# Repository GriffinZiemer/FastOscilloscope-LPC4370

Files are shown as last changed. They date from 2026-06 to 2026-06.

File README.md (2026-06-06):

# 34 MSa/s Dual Channel Oscillscope
A custom design dual channel USB-C oscilloscope built around the NXP LPC4370 (100 pin TFBGA) intended to output to a Python-based graphical display on a connected computer driven by PyQtGraph. The oscilloscope was designed for the Oregon State University Junior Design II course (ECE 342), the project took place over a 10 week term. 
<p float="left">

<img width="1000"" alt="Screenshot 2026-06-05 142354" src="https://github.com/user-attachments/assets/b3b1693e-237f-446d-a00e-379146662170" />
</p>

# Contributors:
Luke Neilson,
Griffin Ziemer, and
Cooper Holm

## Key Features:
* Dual Channel Simulatnuous Sample Rate: 34MSa/s.
* Vertical Resolution: 12-bits.
* Bandwidth: 1MHz.
* Input Voltage Range: +/- 10V with a 10x attenuation probe, +/- 1V with a 1x attenuation probe.
* AC/DC Coupling: Hardware AC/DC coupling using a photo relay to bypass a 100nF capacitor.
* Power: Powered entirely via a standard USB 2.0 connection (nominally drawing 180mA), with a visible LED power indicator.
* User Interface: High-speed display which responds to user input in an average of 0.350 milliseconds

## Hardware Architecture
* Power Block: 5V USB input regulated down to 3.3V digital rail using a TpS79533 LDO. An LM27762 charge pump provides +/- 1.65V rails for some of the Analog Front End op-amps. A 500mV Vref offset is generated off a ferrite bead from the 3.3V line.
* Analog Front End: Incoming signals pass through the coupling and overvoltage protection stages into a variable gain attenuation controlled by TMUX1134 precision analog multiplexers. OPA356 op-amps shift and scale the signals to fit the 100mV to 900mV window required by the LPC4370's ADC.
* Microcontroller: The system uses an LPC4370's Direct Memory Access controller to write 12-bit ADC results into an SRAM buffer without CPU overhead, ensuring maximum throughput.

## Software & Protocol Stack
* Firmware: The backend firmware configures the Analog Front End Gain and AC/DC photorelays at boot. It serializes DMA transfers into packets containing 0xAA start byte, the daya type, sample count, payload and an XOR checksum, transmitting them over a USB CDC link.
* Host Bridge & GUI: A worker thread deserializes incoming packets, verifies the checksum, and translates raw ADC counts into real voltage based on the current user scale. The UI is built using PyQt5 and pyqtgraph. To maximize accessibilty, Channel 1 is rendered in blue and Channel 2 in pink, complying with NCEAS colorblind-safe guidelines.

## Team Work Breakdown
* Luke Neilson: MCU block design, PCB layout (Versions 1 and 2), initial Display blcok design, and Teensy 4.0 backup implementation.
* Griffin Ziemer: User Input GUI, Backend firmware, host bridge protocol serialization/deserialization, and integration of the display.
* Cooper Holm: Power supply block design, Analog Frent End architecture.

## Future Improvements
 ### To Be Implemented with Current Hardware
  Due to the 10 week timeline, the project ran out of time to implement all of the features designed in hardware in the software.
  * Real time control over the attenuation paths, allowing selection between gain path: 0.256x, 0.833x, 2.566x, and 10x
  * Real time control over AC/DC coupling, allowing selection between gain path: 0.256x, 0.833x, 2.566x, and 10x
  * Configure PLLs to create an exact 80MHz clock for the ADC to reach the maximum hardware sampling rate
  * Flash firmware to the non-volitile memory
 ### Version 3 of the PCB Improvements
  * Minimize digital analog cross talk: The bandwidth was limited because a more aggressive RC filter at the ADC input was required because of the noise from the digital components (LPC 4370 and a 12MHz external clock).
   * Shorten the signal path from the analog front end to the ADC.
   * Use differential pair drivers to create differential pairs to go from the analog front end to the ADC

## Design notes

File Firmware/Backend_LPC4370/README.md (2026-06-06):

# Backend_LPC4370 (LPC4370 Firmware)

This is the Backend block for the FastOscilloscope project, written as C firmware that runs on the LPC4370 MCU. It does four things:

1. Brings up the system clock (12 MHz crystal to 204 MHz core, 68 MHz HSADC)
2. Drives the analog front end GPIOs (gain MUX plus AC/DC coupling)
3. Captures bursts of 12 bit ADC samples via the on chip HSADC
4. Talks to the laptop over USB CDC using our framed packet protocol

On the laptop side, `Code/host_bridge.py` speaks the same protocol and hands packets to the User Input and Display blocks.

## Status, read this before flashing

I want to be upfront about what's actually done. The firmware is structurally complete. Every file the project needs exists, every function the build references is defined, and the byte level protocol is fully cross validated against the laptop side with no hardware (see "Verifying it works" below).

What's NOT done yet:

* I haven't compiled it in MCUXpresso on a Windows box, only laptop side static analysis. So a couple of include paths or library link names may need small tweaks once the project is imported.
* The DMA routing from the HSADC FIFO into SRAM goes through the LPC4370's GIMA (DMA mux). LPCOpen ships no LPC4370 specific example for this and I wasn't going to guess. Fallback is polled reads from `HSADC->LAST_SAMPLE` for the first bring up, see TODOs.
* Has not been run on real silicon. Pin map values came from Luke's schematic but I'd verify a couple with a multimeter before flashing.

So: this gets you a project that compiles and links into a flashable binary. Whether HSADC samples actually land in the right buffer at the right rate is a hardware day discovery.

## Source layout

```
Firmware/Backend_LPC4370/
|-- inc/
|   |-- pin_map.h          Named pin defines from Luke's pin assignment table
|-- src/
|   |-- main.c             Superloop: drain USB RX, parse, dispatch, push USB TX
|   |-- proto.[ch]         Packet parser/builder (must match host_bridge.py byte by byte)
|   |-- afe.[ch]           AFE GPIO control (gain MUX, AC/DC coupling switch)
|   |-- adchs.[ch]         HSADC init plus DMA driven burst capture plus trigger comparator
|   |-- clock.[ch]         CGU setup: 204 MHz core (PLL1), 68 MHz HSADC (IDIVA from PLL1)
|   |-- usb_cdc.[ch]       Thin wrapper around the vendored LPCOpen CDC code
|   |-- lpcopen_cdc/       Vendored LPCOpen USB CDC sources (see header below)
|       |-- app_usb_cdc.c  Refactored from LPCOpen's cdc_main.c (USB stack init)
|       |-- cdc_vcom.c/.h  Virtual COM port class implementation
|       |-- cdc_desc.c     USB device plus endpoint descriptors
|       |-- app_usbd_cfg.h ROM driver config plus USB stack memory layout
|       |-- board.h        Tiny shim so the vendored files compile without bambino
```

`lpcopen_cdc/` is the LPCOpen `usbd_rom_cdc_vcom` example, copied in and refactored so we expose `app_usb_cdc_init()` instead of a `main()`. NXP's permissive license is in each file's header.

## What you need installed first

On the host (the machine you'll build firmware on):

* MCUXpresso IDE, NXP's Eclipse based IDE for LPC parts. https://www.nxp.com/.../mcuxpresso-software-and-tools-:MCUXpresso-IDE
* LPCOpen LPC18xx/43xx package. Provides `lpc_chip_43xx`, the chip driver library we link against. NXP's download requires a free account. The file we want is something like `lpcopen_3_02_lpcxpresso_nxp_lpcxpresso_4337.zip`.
* An SWD debug probe (LPC-Link2, J-Link, or equivalent).

On the laptop you'll talk to the board with:

* Python 3.10 or newer
* `pip install pyserial pyqt5 pyqtgraph numpy`
* The COM port the board enumerates as. Look in Device Manager, Ports on Windows, or `ls /dev/tty.usbmodem*` on macOS/Linux.

## How to build it

### 1. Pull LPCOpen into MCUXpresso

In MCUXpresso click "Import project(s) from file system" in the Quickstart Panel, point at the LPCOpen zip, and check `lpc_chip_43xx` in the import dialog. Build it once. You should see a green `lpc_chip_43xx.a` show up under `Debug/`.

You do NOT need to import LPCOpen's CDC example. We vendored it in `src/lpcopen_cdc/` so we don't depend on it being available.

You also do NOT need to import a `lpc_board_*` library. We wrote our own minimal board init (it's inside `clock.c` plus `afe_init()` plus the vendored `board.h` shim).

### 2. Create the Backend project

1. File, New, C Project, NXP, LPC4300, LPC4370.
2. Empty Project template. Don't let it copy in any LPCOpen sources. We want our own `src/` and `inc/` to be the only sources.
3. Set the project location to this folder (`Firmware/Backend_LPC4370`). MCUXpresso writes `.cproject` and `.project` here.

### 3. Wire up the includes plus library link

In Project Properties, C/C++ Build, Settings:

* MCU C Compiler, Includes: add
  * `../inc`
  * `../../lpc_chip_43xx/inc`
  * `../src/lpcopen_cdc` (so `#include "cdc_vcom.h"` and friends resolve)
* MCU Linker, Libraries: add `lpc_chip_43xx` under Libraries (-l) and the matching `Debug` or `Release` path under Library search path (-L).
* Project References: tick `lpc_chip_43xx` so it rebuilds when needed.

### 4. Build

Right click the project, Build Project. You should get a clean build with no warnings about missing functions. If you see `undefined reference to vcom_*` or `find_IntfDesc`, check that `src/lpcopen_cdc/` was added to the source folders. Sometimes MCUXpresso misses subdirs.

### 5. Flash

1. Connect the SWD probe (TMS/SWDIO, TCK/SWDCLK, GND, VTREF).
2. Run, Debug As, MCUXpresso IDE LinkServer Debug.
3. Make sure the boot button (P2_8) is NOT held down at reset.

## First time on hardware, staged bring up

Don't go straight to "run main.py and look at waveforms." Things will fail and you won't know where. Do these milestones in order. Each one de risks the next.

**Milestone 1: blink the Neopixel.** Add a temporary 1 Hz toggle on `NEOPIXEL` (P1_6) before `usb_cdc_init()` in `main()`. If the LED blinks, your toolchain plus flash plus clock are working. Remove the test code when done.

**Milestone 2: USB enumerates.** With main() back to normal, plug the USB cable into the laptop. Open Device Manager (Windows) and watch for a new "USB Serial Device (COMx)". If it shows up, the CDC stack is alive.

**Milestone 3: command bytes round trip.** With the device enumerated, from the laptop:
```
python Code/tests/test_host_bridge.py --port COM5 --log-packets
```
You should see TX packet hex traced, and ideally no errors. This proves the host can write bytes that reach the device's USB stack.

**Milestone 4: AFE pins toggle.** Put a scope or multimeter on `CH1_SEL1..4`. Send a few `set_vdiv` commands from `Code/main.py` and watch the SEL lines flip one hot. The `afe_set_gain()` function is strictly break before make so you should never see two SELs high at the same time.

**Milestone 5: HSADC produces data.** Feed a known DC voltage (1.0 V from a battery or bench supply) through the AFE input. Send `set_vdiv` 1 V/div, then `run`. The Display should show a flat line at roughly 1.0 V. If it shows zero or noise, the issue is in the HSADC config (probably the DMA routing, see TODOs).

**Milestone 6: real waveform.** Function generator into AFE input, live waveform on `python Code/main.py --port COM5`. This is the "Backend block fully works" demo.

## Verifying it works

Some of this you can verify before hardware exists. The protocol layer is fully testable on a laptop.

### Without hardware (works on any laptop right now)

```
# All 6 host side tests
python Code/tests/test_host_bridge.py --all

# Cross validate firmware proto.c against host_bridge.py (Test 7)
# Requires gcc on PATH; on Windows install MinGW w64
Code\tests\native\build_proto.bat
python Code\tests\test_proto_parity.py

# AFE control logic unit test (Test 8)
# Same gcc requirement; compiles firmware afe.c against mocked GPIO calls
Code\tests\native\afe_test\build_afe.bat
python Code\tests\test_afe_unit.py
```

Test 7 compiles our actual firmware `proto.c` into a DLL, loads it via ctypes, and checks that every command and data packet round trips byte by byte between the C and Python implementations. Test 8 does the same trick with `afe.c`, recording every GPIO call and verifying the break before make and one hot rules hold. Together they fully verify the protocol and AFE control layer properties of all three Backend interfaces without ever touching hardware. Worth running before plugging the board in just to confirm your environment is sane.

### With hardware

```
# Same test, real device
python Code/tests/test_host_bridge.py --port COM5 --log-packets
python Code/tests/test_host_bridge.py --port COM5 --verify-checksums
python Code/tests/test_host_bridge.py --port COM5 --debug-threads
```

Tests 4 and 5 (inject known patterns or corrupt packets) stay on MockMCU because they need to control the MCU's outgoing bytes, which a real device won't let you do.

## Known issues and TODOs

These are real gaps, not "make sure to verify" stuff. They need work either on hardware or with the LPCOpen reference in hand.

| File | What's wrong or missing |
|---|---|
| `adchs.c` | DMA from HSADC FIFO into SRAM needs the LPC4370 GIMA setup. LPCOpen has no example. Fallback: polled reads from `HSADC->LAST_SAMPLE` in main superloop. |
| `adchs.c` | Sample rate math assumes BASE_ADCHS_CLK = 68 MHz exactly. Verify on hardware with a known input frequency. |
| `clock.c` | Should work as is but I haven't actually scoped the ADCHS clock pin to confirm 68 MHz. |
| `main.c` | Trigger comparator behavior is "best guess" from UM10503 section 47. The threshold to edge mapping might be inverted. Check with a known signal. |
| `usb_cdc.c` | If you see CDC TX truncation under load, bump `g_rxBuff` size in `app_usb_cdc.c` or add a software TX ring. Default is fine for command plus 2 KB ADC bursts. |

## Some implementation notes (for whoever picks this up next)

**Why 68 MHz on HSADC instead of 80 MHz?** 80 MHz from a 12 MHz crystal requires PLL0AUDIO with non integer M, N, P values, which I tried and gave up on. PLL1 divided by 3 gives an exact 68 MHz, uses only the documented `Chip_Clock_*` helpers, and still gives 165 times the project's 200 kHz per channel customer requirement. Swap in PLL0AUDIO later if we really need 80 MHz.

**Why is HSADC called ADCHS in our headers?** NXP's manual uses both names for the same peripheral. LPCOpen settled on `Chip_HSADC_*` and `LPC_HSADC`, so the C code does too. Our public API is `adchs_*` to match the team wide "ADCHS" terminology in the system block diagram.

**Why is the `set_trigger` command split into 3 packets on the wire?** Block 1's GUI emits one big `set_trigger` dict with level, mode, and source. The host side `serialize_command()` expands that into three back to back on wire packets (`SET_TRIGGER_LEVEL`, `SET_TRIGGER_MODE`, `SET_TRIGGER_SOURCE`) because (a) it keeps each packet at most 7 bytes and (b) it lets the firmware update one field without touching the others. The firmware caches all three and re applies the comparator on every update.

**Why is `afe_set_gain()` break before make?** Some analog MUXes are make before break and can briefly forward two signal paths to the ADC during a gain change. Driving all four SELs low first, then asserting the new one, gives us a clean (briefly silent) switch instead of a crosstalk glitch.

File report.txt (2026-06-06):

Info: X scale constrained.
Info: Y scale constrained.
Plotted to 'C:\Users\coope\Documents\ECE342\FastOscilloscope-LPC4370\KiCAD\MCU-F_Cu.gbr'.
Plotted to 'C:\Users\coope\Documents\ECE342\FastOscilloscope-LPC4370\KiCAD\MCU-In1_Cu.gbr'.
Plotted to 'C:\Users\coope\Documents\ECE342\FastOscilloscope-LPC4370\KiCAD\MCU-In2_Cu.gbr'.
Plotted to 'C:\Users\coope\Documents\ECE342\FastOscilloscope-LPC4370\KiCAD\MCU-B_Cu.gbr'.
Plotted to 'C:\Users\coope\Documents\ECE342\FastOscilloscope-LPC4370\KiCAD\MCU-F_Paste.gbr'.
Plotted to 'C:\Users\coope\Documents\ECE342\FastOscilloscope-LPC4370\KiCAD\MCU-B_Paste.gbr'.
Plotted to 'C:\Users\coope\Documents\ECE342\FastOscilloscope-LPC4370\KiCAD\MCU-F_Silkscreen.gbr'.
Plotted to 'C:\Users\coope\Documents\ECE342\FastOscilloscope-LPC4370\KiCAD\MCU-B_Silkscreen.gbr'.
Plotted to 'C:\Users\coope\Documents\ECE342\FastOscilloscope-LPC4370\KiCAD\MCU-F_Mask.gbr'.
Plotted to 'C:\Users\coope\Documents\ECE342\FastOscilloscope-LPC4370\KiCAD\MCU-B_Mask.gbr'.
Plotted to 'C:\Users\coope\Documents\ECE342\FastOscilloscope-LPC4370\KiCAD\MCU-Edge_Cuts.gbr'.
Created Gerber job file 'C:\Users\coope\Documents\ECE342\FastOscilloscope-LPC4370\KiCAD\MCU-job.gbrjob'.
Info: Done.

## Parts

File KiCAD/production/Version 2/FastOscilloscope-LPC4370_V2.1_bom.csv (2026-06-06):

Designator | Footprint | Quantity | Value | LCSC Part #
+1V65, -1V65, 1_SEL1, 1_SEL2, 1_SEL3, 1_SEL4, 2_SEL1, 2_SEL2, 2_SEL3, 2_SEL4, 3V3, 5V1, CHANNEL1, OFF1, SSR_1, SSR_2, TP12 | TestPoint_Pad_1.0x1.0mm | 17 | TestPoint
BNC1, BNC2 | BNC Connector 2.0 | 2 | 3GHz
BOOT1, RESET1 | KEY-SMD | 2 | Push Button
C1, C10, C11, C12, C16, C21, C23, C24, C26, C27, C28, C3, C30, C31, C32, C34, C36, C37, C38, C4, C40, C41, C42, C45, C47, C5, C6, C7, C8, C9 | 0402 | 30 | 0.1uF
C13, C18 | 0603 | 2 | 4.7uF
C14, C19, C20 | 0603 | 3 | 2.2uF
C15, C22, C44 | 0603 | 3 | 1uF
C17, C46 | 0603 | 2 | 10uF
C2, C48 | 0402 | 2 | 12pF
C25, C35 | 1206 | 2 | 100nF
C29, C39 | 0603 | 2 | 5pF
C33, C43 | 0603 | 2 | 330p
D1, D2 | SOT-23-3_L2.9-W1.6-P1.90-LS2.8-BR ESD | 2 | Diode Array
FB1 | L0603 (Ferrite Bead) | 1 | FerriteBead
LED1 | PSU LED | 1 | PSU LED
MCU1 | LPC4370 | 1 | LPC4370FET100E
NEOPIXEL1 | Neopixel | 1 | LED1
R1, R10, R11, R12, R6, R7, R9 | 0402 | 7 | 10k
R14 | 0603 | 1 | 75k
R15 | 0603 | 1 | 200k
R16 | 0603 | 1 | 68k
R17 | 0603 | 1 | 24k
R18, R30 | 0603 | 2 | 390
R19, R31 | 0603 | 2 | 1.2k
R2 | 0402 | 1 | 0
R20, R32 | 0603 | 2 | 3.9k
R21, R33 | 0603 | 2 | 470
R22, R34, R44 | 0603 | 3 | 100
R23, R35 | 1206 | 2 | 1M
R24, R36 | 0805 | 2 | 2k
R25, R26, R27, R28, R37, R38, R39, R40, RF1, RF2 | 0603 | 10 | 1k
R29, R41 | 0603 | 2 | 47
R42, R43 | 0603 | 2 | 5.1k
R8 | 0402 | 1 | 12k
U1 | Flash footprint 2.0 | 1 | Flash
U10, U13, U14, U15, U8, U9 | DBV5-OPAMP | 6 | OPA356AIDBVR
U11, U6 | VSON-4_L1.5-W2.5-P0.80-BL-DCAC-SWITCH | 2 | TLP3441TP_F
U12, U7 | TSSOP20_PW_TEX-MUX | 2 | TMUX1134PWR
U2 | PinHeader_2x05_P2.54mm_Vertical | 1 | Header
U3 | SOT-223-6_L6.5-W3.5-P1.27-BL (LDO2.0) | 1 | LDO
U4 | WSON-12_L3.0-W2.0-P0.50-BL-EP (Charge Pump) | 1 | LM27762DSSR
U5 | UJ_6_ADI | 1 | ADR130BUJZ-REEL7
USB2 | USB2.0 | 1 | USB1
Y1 | XTAL_ABM3B-12.000MHZ-10-1-U-T | 1 | Passive Oscillator

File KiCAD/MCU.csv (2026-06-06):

Reference | Value | Datasheet | Footprint | Qty | DNP | Supplier Part | Part type
BNC1,BNC2 | 3GHz | https://item.szlcsc.com/datasheet/DOSIN-801-0038/747625.html | JLCPCB_Custom_Parts:BNC Connector 2.0 | 2 | DNP | C709673 | Extended
C1,C2,C3,C4,C5,C6,C7,C8,C9,C10,C11,C12,C16,C21,C23,C24,C26,C27,C28,C30,C31,C32,C34,C36,C37,C38,C40,C41,C42,C45,C47 | 0.1uF |  | Capacitor_SMD:C_0402_1005Metric | 31 |  | C1525 | Basic
C13,C18 | 4.7uF |  | Capacitor_SMD:C_0603_1608Metric | 2 |  | C19666 | Basic
C14,C19,C20 | 2.2uF |  | Capacitor_SMD:C_0603_1608Metric | 3 |  | C23630 | Basic
C15,C22,C44 | 1uF |  | Capacitor_SMD:C_0603_1608Metric | 3 |  | C15849 | Basic
C17,C46 | 10uF |  | Capacitor_SMD:C_0603_1608Metric | 2 |  | C96446 | Basic
C25,C35 | 100nF |  | Capacitor_SMD:C_1206_3216Metric | 2 | DNP | C303949 | Extended
C29,C39 | 5pF |  | Capacitor_SMD:C_0603_1608Metric | 2 | DNP | C49326336 | Extended
C33,C43 | 330p |  | Capacitor_SMD:C_0603_1608Metric | 2 |  | C1664 | Basic
C48 | 100pF |  | Capacitor_SMD:C_0603_1608Metric | 1 |  | C14858 | Basic
D1,D2 | Diode Array |  | JLCPCB_Custom_Parts:SOT-23-3_L2.9-W1.6-P1.90-LS2.8-BR ESD | 2 |  | C2500 | Basic
FB1 | FerriteBead |  | JLCPCB_Custom_Parts:L0603 (Ferrite Bead) | 1 |  | C14709 | Basic
H1 | Debug Header |  | JLCPCB_Custom_Parts:Debug Header | 1 | DNP | C5155080 | Extended
LED1 | PSU LED |  | JLCPCB_Custom_Parts:PSU LED | 1 |  | C2290 | Basic
MCU1 | LPC4370FET100E | LPC4370FET100E | JLCPCB_Custom_Parts:LPC4370 | 1 |  | C1020255 | Extended
Neopixel1 | LED1 | https://item.szlcsc.com/datasheet/SKC6812RGBW-WS-B/6248995.html | JLCPCB_Custom_Parts:Neopixel | 1 | DNP | C5380879 | NA
R1,R4,R6,R7,R9,R10,R11,R12,R13 | 10k |  | Resistor_SMD:R_0402_1005Metric | 9 |  | C25744 | Basic
R8 | 12k |  | Resistor_SMD:R_0603_1608Metric | 1 |  | C22790 | Basic
R14 | 75k |  | Resistor_SMD:R_0603_1608Metric | 1 |  | C23242 | Basic
R15 | 200k |  | Resistor_SMD:R_0603_1608Metric | 1 |  | C25811 | Basic
R16 | 68k |  | Resistor_SMD:R_0603_1608Metric | 1 |  | C23231 | Basic
R17 | 24k |  | Resistor_SMD:R_0603_1608Metric | 1 |  | C23352 | Basic
R18,R30 | 390 |  | Resistor_SMD:R_0603_1608Metric | 2 |  | C23151 | Basic
R19,R31,R45 | 1.2k |  | Resistor_SMD:R_0603_1608Metric | 3 |  | C22765 | Basic
R20,R32 | 3.9k |  | Resistor_SMD:R_0603_1608Metric | 2 |  | C23018 | Basic
R21,R33 | 470 |  | Resistor_SMD:R_0603_1608Metric | 2 |  | C23179 | Basic
R22,R34,R44 | 100 |  | Resistor_SMD:R_0603_1608Metric | 3 |  | C22775 | Basic
R23,R35 | 1M |  | Resistor_SMD:R_1206_3216Metric | 2 | DNP | C2989128 | Extended
R24,R36 | 2k |  | Resistor_SMD:R_0805_2012Metric | 2 |  | C17604 | Basic
R25,R26,R27,R28,R37,R38,R39,R40,R46,Rf1,Rf2 | 1k |  | Resistor_SMD:R_0603_1608Metric | 11 |  | C21190 | Basic
R29,R41 | 47 |  | Resistor_SMD:R_0603_1608Metric | 2 |  | C23182 | Basic
R42,R43 | 5.1k |  | Resistor_SMD:R_0603_1608Metric | 2 |  | C23186 | Basic
SW1,SW2 | Push Button |  | JLCPCB_Custom_Parts:KEY-SMD | 2 | DNP | C49234124 | Extended
TP1,TP2,TP3,TP5,TP6,TP11,TP12,TP15 | TestPoint |  | TestPoint:TestPoint_Pad_1.0x1.0mm | 8 | DNP
TP7 | CH1_SEL1 |  | TestPoint:TestPoint_Pad_1.0x1.0mm | 1 | DNP
TP8 | CH2_SEL1 |  | TestPoint:TestPoint_Pad_1.0x1.0mm | 1 | DNP
TP9 | CH1_SEL2 |  | TestPoint:TestPoint_Pad_1.0x1.0mm | 1 | DNP
TP10 | CH2_SEL2 |  | TestPoint:TestPoint_Pad_1.0x1.0mm | 1 | DNP
TP13 | CH1_SEL3 |  | TestPoint:TestPoint_Pad_1.0x1.0mm | 1 | DNP
TP14 | CH2_SEL3 |  | TestPoint:TestPoint_Pad_1.0x1.0mm | 1 | DNP
TP16 | CH2_SELSSR |  | TestPoint:TestPoint_Pad_1.0x1.0mm | 1 | DNP
TP18 | CH1_SEL4 |  | TestPoint:TestPoint_Pad_1.0x1.0mm | 1 | DNP
TP19 | CH2_SEL4 |  | TestPoint:TestPoint_Pad_1.0x1.0mm | 1 | DNP
U1 | Flash |  | JLCPCB_Custom_Parts:Flash Memory | 1 |  | C97521 | Basic
U2 | 12MHz | https://item.szlcsc.com/datasheet/ECS-TXO-2520MV-120-AN-TR/2694029.html | JLCPCB_Custom_Parts:OSC-SMD_4P-L2.5-W2.0-BL (Oscillator2.0) | 1 | DNP | C2602137 | Extended
U3 | LDO | https://www.ti.com/cn/lit/gpn/tps795 | JLCPCB_Custom_Parts:SOT-223-6_L6.5-W3.5-P1.27-BL (LDO2.0) | 1 | DNP | C105264 | Extended
U4 | LM27762DSSR | https://www.ti.com/lit/gpn/lm27762 | JLCPCB_Custom_Parts:WSON-12_L3.0-W2.0-P0.50-BL-EP (Charge Pump) | 1 | DNP | C473398 | Extended
U5 | ADR130BUJZ-REEL7 | https://www.analog.com/media/en/technical-documentation/data-sheets/ADR130.pdf | JLCPCB_Custom_Parts:UJ_6_ADI | 1 | DNP | C659476 | Extended
U6,U11 | TLP3441TP_F | https://toshiba.semicon-storage.com/info/docget.jsp?did=29491&prodName=TLP3441 | JLCPCB_Custom_Parts:VSON-4_L1.5-W2.5-P0.80-BL-DCAC-SWITCH | 2 | DNP | C2152054 | Extended
U7,U12 | TMUX1134PWR | https://www.ti.com/lit/gpn/tmux1134 | JLCPCB_Custom_Parts:TSSOP20_PW_TEX-MUX | 2 | DNP | C2866620 | Extended
U8,U9,U10,U13,U14,U15 | OPA356AIDBVR | https://www.ti.com/lit/gpn/opa356 | JLCPCB_Custom_Parts:DBV5-OPAMP | 6 | DNP | C183100 | Extended
USB2 | USB1 | https://item.szlcsc.com/datasheet/161N-4PSD43/8579678.html | JLCPCB_Custom_Parts:USB2.0 | 1 | DNP | C7500847 | Extended

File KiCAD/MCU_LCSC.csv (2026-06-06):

Reference | Value | Datasheet | Footprint | Qty | DNP | Supplier Part | Part type | Person
BNC1,BNC2 | 3GHz | https://item.szlcsc.com/datasheet/DOSIN-801-0038/747625.html | JLCPCB_Custom_Parts:BNC Connector 2.0 | 2 |  | C709673 | Extended | JDII
C25,C35 | 100nF |  | Capacitor_SMD:C_1206_3216Metric | 2 |  | C303949 | Extended | JDII
C29,C39 | 5pF |  | Capacitor_SMD:C_0603_1608Metric | 2 |  | C49326336 | Extended | JDII
H1 | Debug Header |  | JLCPCB_Custom_Parts:Debug Header | 1 |  | C5155080 | Extended | JDII
MCU1 | LPC4370FET100E | LPC4370FET100E | JLCPCB_Custom_Parts:LPC4370 | 1 |  | C1020255 | Extended | JDII
R23,R35 | 1M |  | Resistor_SMD:R_1206_3216Metric | 2 |  | C2989128 | Extended | JDII
SW1,SW2 | Push Button |  | JLCPCB_Custom_Parts:KEY-SMD | 2 |  | C49234124 | Extended | JDII
U2 | 12MHz | https://item.szlcsc.com/datasheet/ECS-TXO-2520MV-120-AN-TR/2694029.html | JLCPCB_Custom_Parts:OSC-SMD_4P-L2.5-W2.0-BL (Oscillator2.0) | 1 |  | C2602137 | Extended | JDII
U3 | LDO | https://www.ti.com/cn/lit/gpn/tps795 | JLCPCB_Custom_Parts:SOT-223-6_L6.5-W3.5-P1.27-BL (LDO2.0) | 1 |  | C105264 | Extended | JDII
U4 | LM27762DSSR | https://www.ti.com/lit/gpn/lm27762 | JLCPCB_Custom_Parts:WSON-12_L3.0-W2.0-P0.50-BL-EP (Charge Pump) | 1 |  | C473398 | Extended | JDII
U5 | ADR130BUJZ-REEL7 | https://www.analog.com/media/en/technical-documentation/data-sheets/ADR130.pdf | JLCPCB_Custom_Parts:UJ_6_ADI | 1 |  | C659476 | Extended | JDII
U6,U11 | TLP3441TP_F | https://toshiba.semicon-storage.com/info/docget.jsp?did=29491&prodName=TLP3441 | JLCPCB_Custom_Parts:VSON-4_L1.5-W2.5-P0.80-BL-DCAC-SWITCH | 2 |  | C2152054 | Extended | JDII
U7,U12 | TMUX1134PWR | https://www.ti.com/lit/gpn/tmux1134 | JLCPCB_Custom_Parts:TSSOP20_PW_TEX-MUX | 2 |  | C2866620 | Extended | JDII
U8,U9,U10,U13,U14,U15 | OPA356AIDBVR | https://www.ti.com/lit/gpn/opa356 | JLCPCB_Custom_Parts:DBV5-OPAMP | 6 |  | C183100 | Extended | JDII
USB2 | USB1 | https://item.szlcsc.com/datasheet/161N-4PSD43/8579678.html | JLCPCB_Custom_Parts:USB2.0 | 1 |  | C7500847 | Extended | JDII
 |  |  |  | 25 |  | C5301796 |  | Elliot
 |  |  |  | 5 |  | C2881925 |  | Elliot
 |  |  |  | 10 |  | C41368895 |  | Elliot
 |  |  |  | 5 |  | C39832921 |  | Elliot
 |  |  |  | 5 |  | C37328851 |  | Elliot
 |  |  |  | 2 |  | C7422498 |  | Elliot

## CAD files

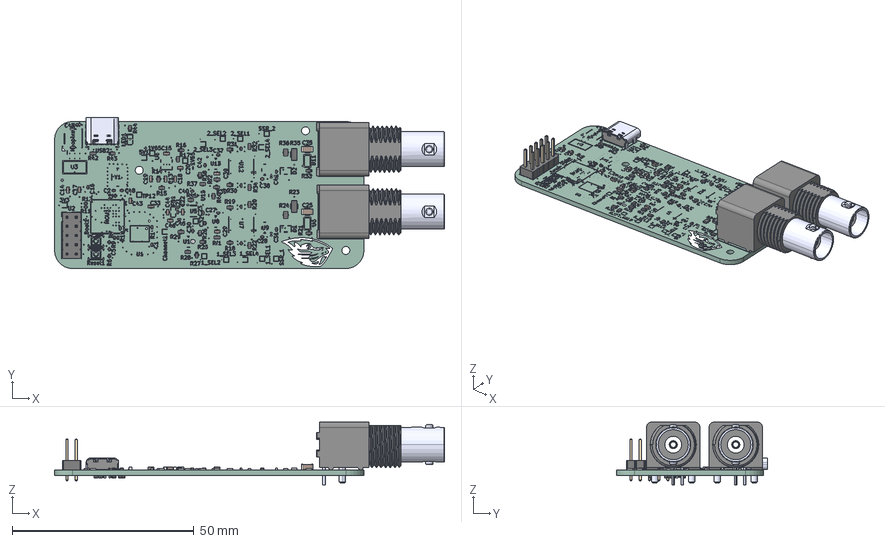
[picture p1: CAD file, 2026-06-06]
KiCAD/Fast_Oscilloscope.step
107.4 x 41.6 x 17.4 mm
C_0402_1005Metric x 32
R_0603_1608Metric x 29
R_0402_1005Metric x 9
PinHeader_2x05_P2.54mm_Vertical
C_1206_3216Metric x 2
C_0603_1608Metric x 14
R_0805_2012Metric x 2
UJ20-C-H-G-SMT-1-P16-TR_UJ20-C-H-G-SMT-1-P16-TR
R_1206_3216Metric x 2
MCU_silkscreen x 2
MCU_PCB

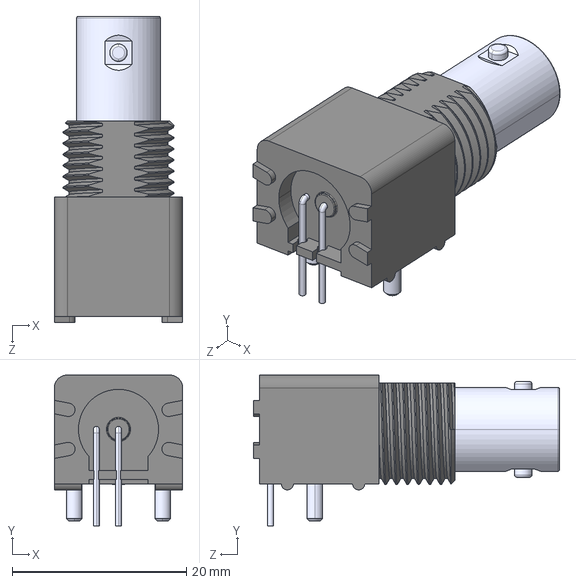
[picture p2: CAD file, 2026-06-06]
KiCAD/Imported 3D Models/BNC_Connector.step
14.8 x 17.4 x 35.2 mm

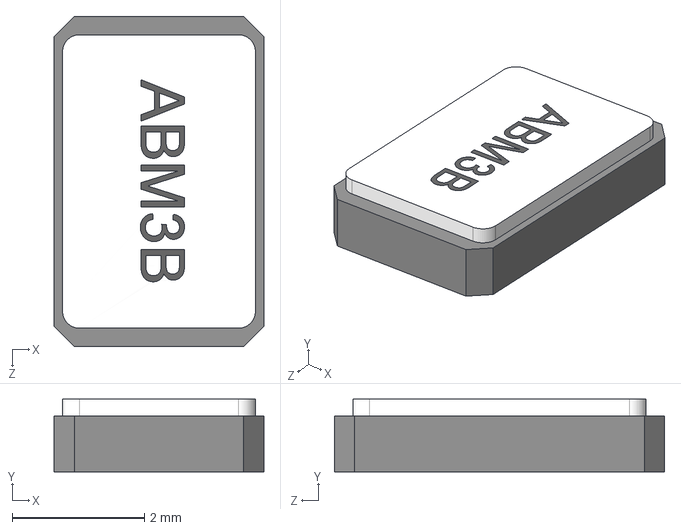
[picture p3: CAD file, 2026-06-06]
KiCAD/Passive_Oscillator/ABM3B-12.000MHZ-10-1-U-T.step
3.18 x 1.10 x 5.00 mm

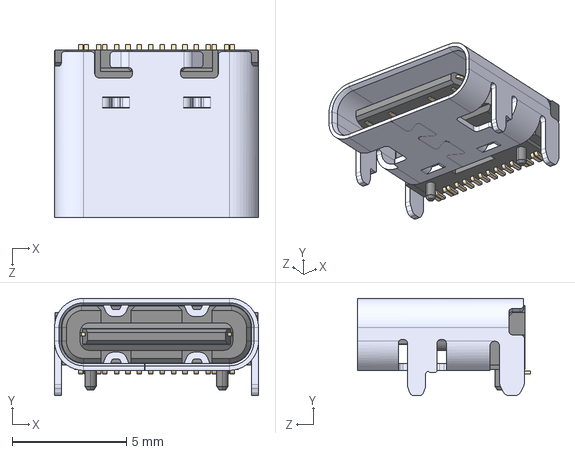
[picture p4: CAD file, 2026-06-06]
KiCAD/Imported 3D Models/USBC.step
8.94 x 4.27 x 7.60 mm

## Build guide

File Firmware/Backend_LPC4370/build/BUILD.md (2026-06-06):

# Building and flashing the firmware

This folder has everything needed to build the LPC4370 firmware from the command
line and flash it over USB, except two things you install once (an Arm compiler
and the NXP chip library). No MCUXpresso IDE required.

## What is in this folder

| File | Role |
|---|---|
| `build.ps1` | The build script. Self locating, run it from anywhere. |
| `lpc4370_ram.ld` | Linker script. Puts the image in local SRAM so it runs from a USB DFU download (volatile, no flash programming). |
| `milestone1_blink.c` | Optional NeoPixel blink image for toolchain bring up (only built into the firmware when you define `MILESTONE1_BLINK`). |
| `vendor/hsadc_18xx_43xx.c` | The HSADC driver. LPCOpen 3.02 ships without it, so this copy comes from LPCOpen 2.12. |
| `vendor/cr_startup_lpc43xx.c` | Reset handler and the section table walk the linker script expects. |
| `vendor/sysinit.c` | `SystemInit` plus `OscRateIn` for the `NO_BOARD_LIB` build. |
| `out/` | Build outputs (`scope.elf` / `.bin` / `.hex` / `.map` / `build.log`). Git ignores this. |

## Install once

1. **Arm GNU bare metal toolchain** (`arm-none-eabi-gcc`). Get the "arm-none-eabi"
   build from the Arm Developer site, or reuse the one the MCUXpresso installer
   drops under `%USERPROFILE%\.mcuxpressotools`. The build auto detects that
   location, or set it yourself:
   ```powershell
   $env:ARM_TOOLCHAIN_BIN = "C:\path\to\arm-none-eabi\bin"
   ```
2. **NXP LPCOpen 3.02** (for the `lpc_chip_43xx` chip library). Download LPCOpen
   3.02 for the LPC4370, unzip it, and either drop it at
   `%USERPROFILE%\lpcopen_3_02` (auto detected) or set:
   ```powershell
   $env:LPCOPEN_DIR = "C:\path\to\lpcopen_3_02"
   ```
3. **NXP LPCScrypt** (only needed to flash a board, not to build). It provides
   `image_manager.exe`, `dfu-util.exe`, and the WinUSB driver that lets the PC
   talk to the board in DFU mode. Typical path:
   `C:\nxp\LPCScrypt_2.1.4_101\bin`.

## Build

```powershell
powershell -ExecutionPolicy Bypass -File Firmware\Backend_LPC4370\build\build.ps1
```

The result is `Firmware\Backend_LPC4370\build\out\scope.bin` (plus `.hex` and
`.elf`). A good build ends with `BUILD OK`.

## Flash (USB C, no probe)

The board is flashless and runs a volatile RAM image, so this is how you load new
firmware. Using the LPCScrypt tools (adjust the path to your install):

1. Put the board in DFU mode: hold BOOT (P2_8) and tap RESET. It shows up as
   VID `0x1FC9` PID `0x000C`.
2. Wrap the image with NXP's boot header, then download:
   ```powershell
   $bin = "C:\nxp\LPCScrypt_2.1.4_101\bin"
   $out = "Firmware\Backend_LPC4370\build\out"
   & "$bin\image_manager.exe" -i "$out\scope.bin" -o "$out\scope.bin.hdr" --bin
   & "$bin\dfu-util.exe" -d 0x1fc9:c -c 0 -i 0 -t 2048 -R -D "$out\scope.bin.hdr"
   ```
   `dfu-util` prints "Invalid DFU suffix signature" at the end. That is a harmless
   warning. "Download done" above it is the real result.
3. After the `-R` reset the board re-enumerates as "LPC USB VCom Port" on a COM
   port (COM4 is typical). That is the port you pass to the host GUI.

Every unplug, reset, or power cycle wipes the RAM image, so re-flash after each.

## Editing the AFE (gain and coupling work)

The control driver is `../src/afe.c` (`afe_set_gain`, `afe_set_coupling_dc`). The
command that reaches it is dispatched in `../src/main.c`. To add the AC/DC
coupling command end to end, follow the steps in the top level
[`README.md`](../../../README.md) under "Continuing development".

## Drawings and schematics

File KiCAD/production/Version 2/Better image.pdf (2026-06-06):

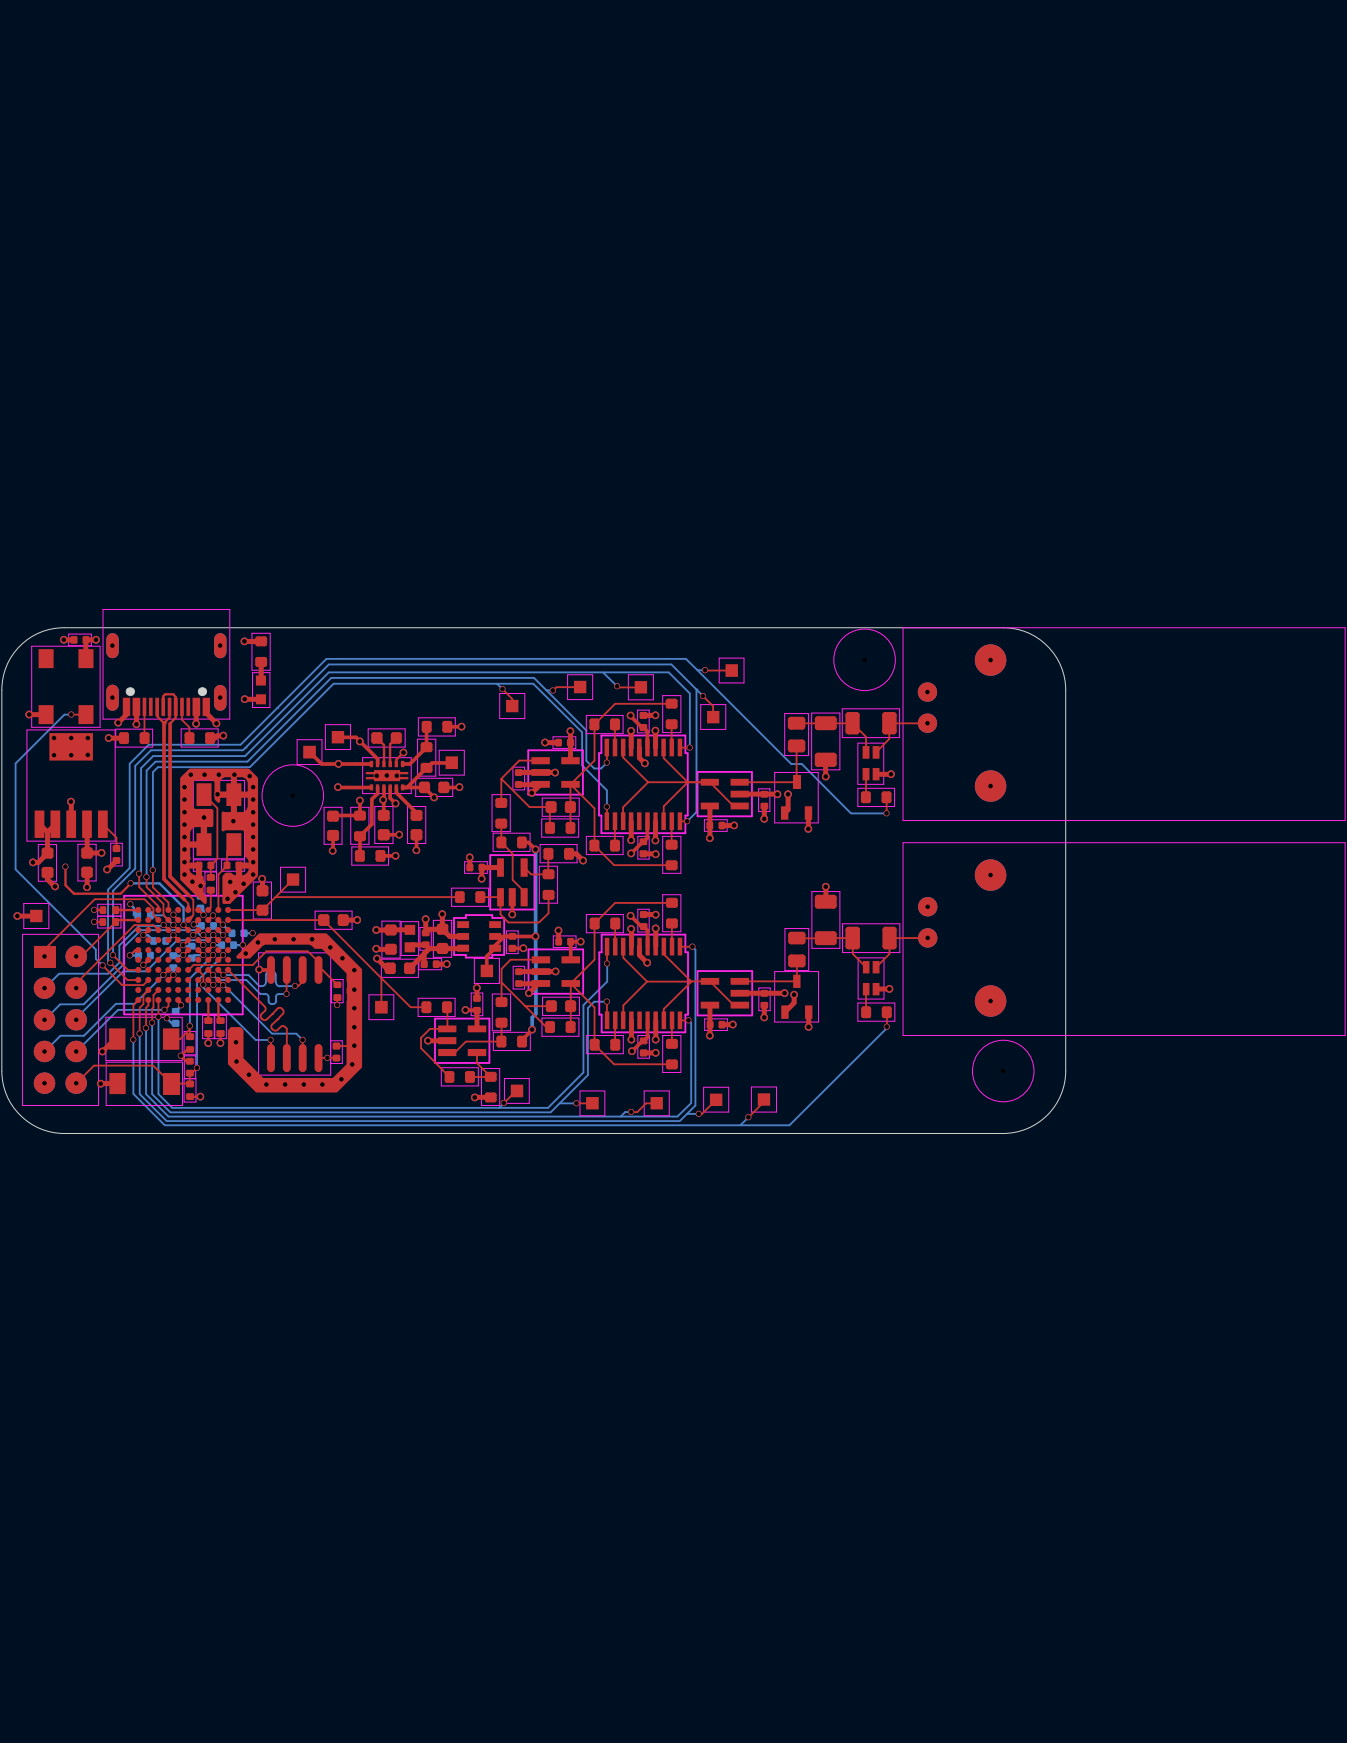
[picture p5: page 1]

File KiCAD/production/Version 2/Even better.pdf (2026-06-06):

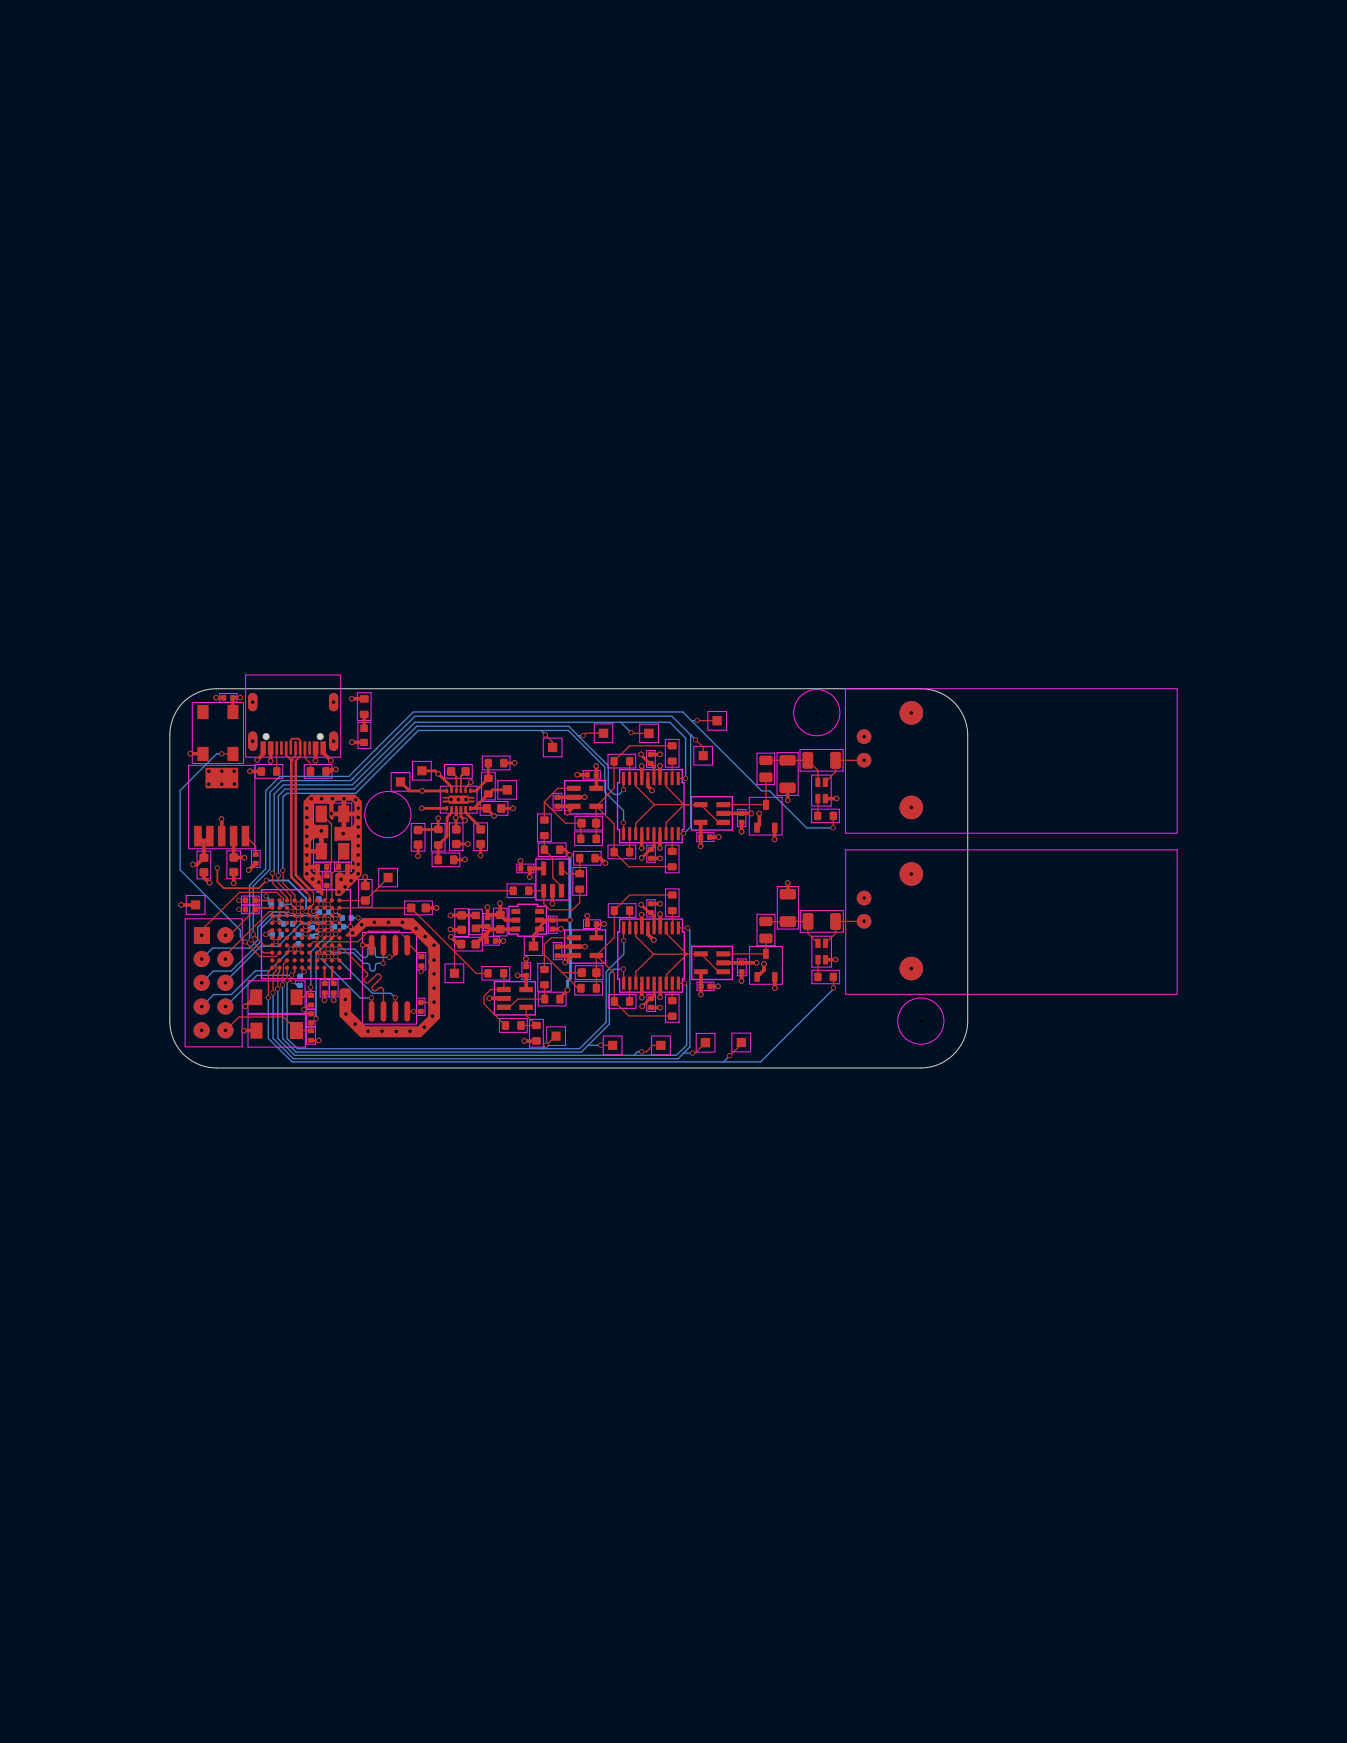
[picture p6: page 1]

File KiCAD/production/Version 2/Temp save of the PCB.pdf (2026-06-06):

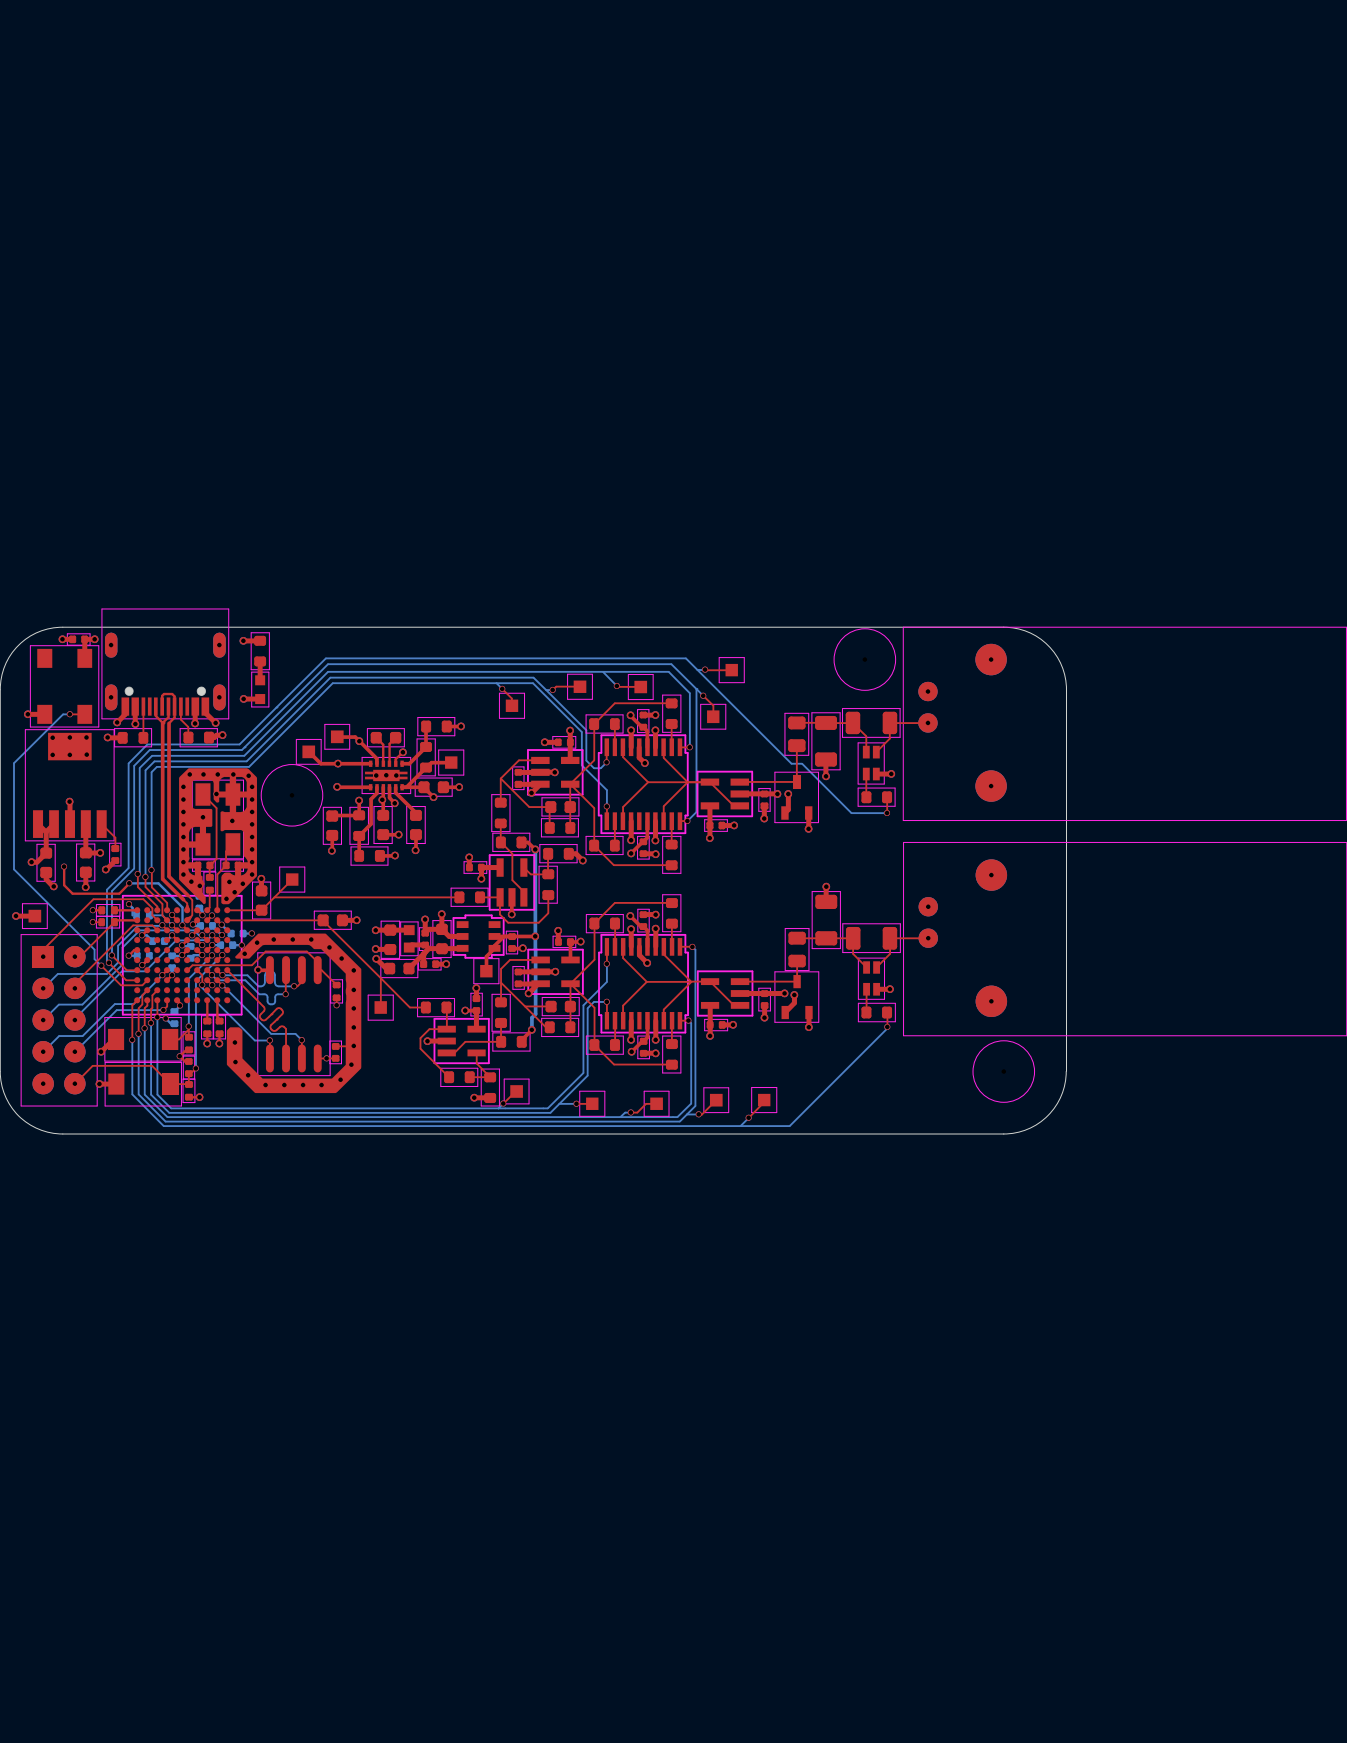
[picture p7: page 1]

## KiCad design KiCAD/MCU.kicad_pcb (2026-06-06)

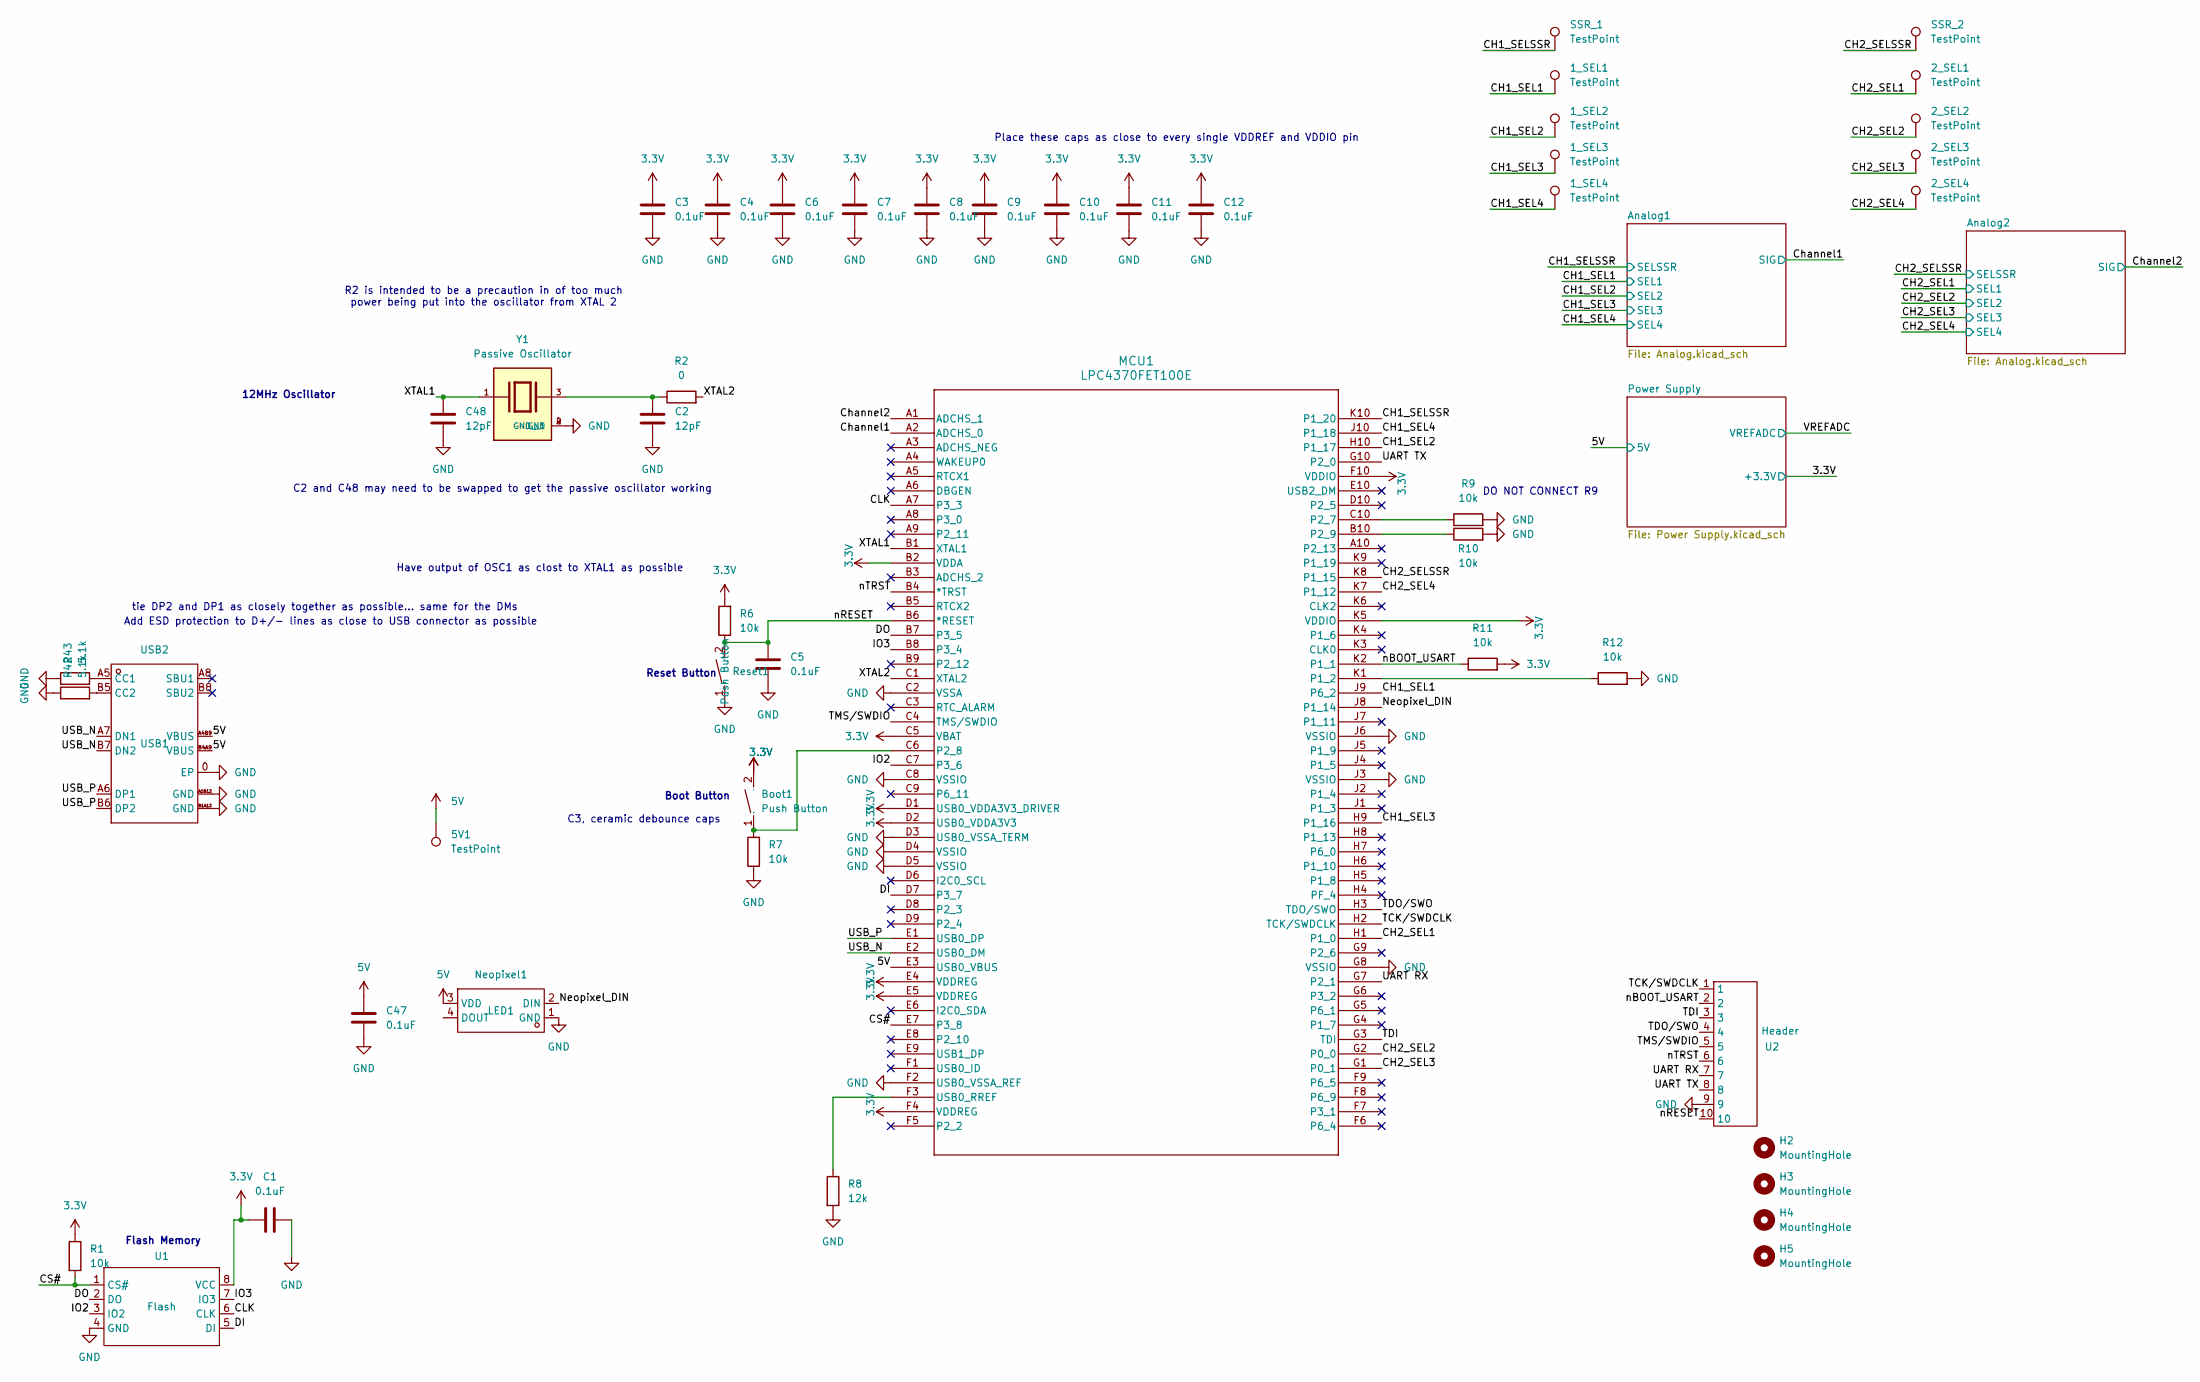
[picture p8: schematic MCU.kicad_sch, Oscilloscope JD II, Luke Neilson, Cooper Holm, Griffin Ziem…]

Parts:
1_SEL1, 1_SEL2, 1_SEL3, 1_SEL4, 2_SEL1, 2_SEL2, 2_SEL3, 2_SEL4, 5V1: TestPoint; TestPoint_Pad_1.0x1.0mm
Boot1: Push Button; KEY-SMD; Manufacturer Part -- mixed values --; LCSC Part Name -- mixed values --
C1, C3, C4, C5, C6, C7, C8, C9, C10, C11, C12, C47: 0.1uF; C_0402_1005Metric; Part type Basic
C2, C48: 12pF; C_0402_1005Metric
H2, H3, H4, H5: MountingHole; MountingHole_2.2mm_M2
MCU1: LPC4370FET100E; LPC4370; Part type Extended
Neopixel1: LED1; Neopixel; Manufacturer Part SKC6812RGBW-WS-B; LCSC Part Name 工作电压5V、发光角度120°、灰度调节256级、数据传输频率800Kbps的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
R1, R6, R7, R9, R10, R11, R12: 10k; R_0402_1005Metric; Part type Basic
R2: 0; R_0402_1005Metric
R8: 12k; R_0402_1005Metric; Part type Basic
R42, R43: 5.1k; R_0603_1608Metric; Part type Basic
Reset1: Push Button; KEY-SMD; Manufacturer Part -- mixed values --; LCSC Part Name -- mixed values --
SSR_1, SSR_2: TestPoint; TestPoint_Pad_1.0x1.0mm
U1: Flash; Flash footprint 2.0; Manufacturer Part -- mixed values --; LCSC Part Name -- mixed values --
U2: Header; PinHeader_2x05_P2.54mm_Vertical
USB2: USB1; USB2.0; Manufacturer Part 161N-4PSD43; LCSC Part Name Type-C 母 弯插
Y1: Passive Oscillator; XTAL_ABM3B-12.000MHZ-10-1-U-T; PARTREV 08.25.15

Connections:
3.3V: Boot1.2, C1.1, C3.2, C4.2, C6.2, C7.2, C8.2, C9.2, C10.2, C11.2, C12.2, MCU1.B2 (VDDA), MCU1.C5 (VBAT), MCU1.D1 (USB0_VDDA3V3_DRIVER), MCU1.D2 (USB0_VDDA3V3), MCU1.E4 (VDDREG), MCU1.E5 (VDDREG), MCU1.F4 (VDDREG), MCU1.F10 (VDDIO), MCU1.K5 (VDDIO), R1.1, R6.2, R11.2, U1.8 (VCC); also elsewhere on the board
5V: 5V1.1 (1_1), C47.1, MCU1.E3 (USB0_VBUS), Neopixel1.3 (VDD), USB2.A4B9 (VBUS), USB2.B4A9 (VBUS); also elsewhere on the board
/CH1_SEL1: 1_SEL1.1 (1_1), MCU1.J9 (P6_2); also elsewhere on the board
/CH1_SEL2: 1_SEL2.1 (1_1), MCU1.H10 (P1_17); also elsewhere on the board
/CH1_SEL3: 1_SEL3.1 (1_1), MCU1.H9 (P1_16); also elsewhere on the board
/CH1_SEL4: 1_SEL4.1 (1_1), MCU1.J10 (P1_18); also elsewhere on the board
/CH1_SELSSR: MCU1.K10 (P1_20), SSR_1.1 (1_1); also elsewhere on the board
/CH2_SEL1: 2_SEL1.1 (1_1), MCU1.H1 (P1_0); also elsewhere on the board
/CH2_SEL2: 2_SEL2.1 (1_1), MCU1.G2 (P0_0); also elsewhere on the board
/CH2_SEL3: 2_SEL3.1 (1_1), MCU1.G1 (P0_1); also elsewhere on the board
/CH2_SEL4: 2_SEL4.1 (1_1), MCU1.K7 (P1_12); also elsewhere on the board
/CH2_SELSSR: MCU1.K8 (P1_15), SSR_2.1 (1_1); also elsewhere on the board
/CLK: MCU1.A7 (P3_3), U1.6 (CLK)
/CS#: MCU1.E7 (P3_8), R1.2, U1.1 (CS#)
/Channel1: MCU1.A2 (ADCHS_0); also elsewhere on the board
/Channel2: MCU1.A1 (ADCHS_1); also elsewhere on the board
/DI: MCU1.D7 (P3_7), U1.5 (DI)
/DO: MCU1.B7 (P3_5), U1.2 (DO)
/IO2: MCU1.C7 (P3_6), U1.3 (IO2)
/IO3: MCU1.B8 (P3_4), U1.7 (IO3)
/Neopixel_DIN: MCU1.J8 (P1_14), Neopixel1.2 (DIN)
/TCK/SWDCLK: MCU1.H2 (TCK/SWDCLK), U2.1
/TDI: MCU1.G3 (TDI), U2.3
/TDO/SWO: MCU1.H3 (TDO/SWO), U2.4
/TMS/SWDIO: MCU1.C4 (TMS/SWDIO), U2.5
/UART RX: MCU1.G7 (P2_1), U2.7
/UART TX: MCU1.G10 (P2_0), U2.8
/USB_N: MCU1.E2 (USB0_DM), USB2.A7 (DN1), USB2.B7 (DN2)
/USB_P: MCU1.E1 (USB0_DP), USB2.A6 (DP1), USB2.B6 (DP2)
/XTAL1: C48.1, MCU1.B1 (XTAL1), Y1.1
/XTAL2: MCU1.C1 (XTAL2), R2.2
/nBOOT_USART: MCU1.K2 (P1_1), R11.1, U2.2
/nRESET: C5.2, MCU1.B6 (*RESET), R6.1, Reset1.2, U2.10
/nTRST: MCU1.B4 (*TRST), U2.6
GND: C1.2, C2.2, C3.1, C4.1, C5.1, C6.1, C7.1, C8.1, C9.1, C10.1, C11.1, C12.1, C47.2, C48.2, MCU1.C2 (VSSA), MCU1.C8 (VSSIO), MCU1.D3 (USB0_VSSA_TERM), MCU1.D4 (VSSIO), MCU1.D5 (VSSIO), MCU1.F2 (USB0_VSSA_REF), MCU1.G8 (VSSIO), MCU1.J3 (VSSIO), MCU1.J6 (VSSIO), Neopixel1.1 (GND), R7.1, R8.2, R9.2, R10.2, R12.2, R42.1, R43.1, Reset1.1 (GND), U1.4 (GND), U2.9, USB2.0 (EP), USB2.A1B12 (GND), USB2.B1A12 (GND), Y1.2 (GND), Y1.4 (GND__1); also elsewhere on the board
unnamed: Boot1.1 (GND), MCU1.C6 (P2_8), R7.2
unnamed: C2.1, R2.1, Y1.3
unnamed: MCU1.K1 (P1_2), R12.1
unnamed: MCU1.C10 (P2_7), R9.1
unnamed: MCU1.B10 (P2_9), R10.1
unnamed: MCU1.F3 (USB0_RREF), R8.1
unnamed: R43.2, USB2.A5 (CC1)
unnamed: R42.2, USB2.B5 (CC2)

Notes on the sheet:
DO NOT CONNECT R9
Place these caps as close to every single VDDREF and VDDIO pin
Have output of OSC1 as clost to XTAL1 as possible
Boot Button
C3, ceramic debounce caps
Flash Memory
Reset Button
R2 is intended to be a precaution in of too much power being put into the oscillator from XTAL 2
Add ESD protection to D+/- lines as close to USB connector as possible
tie DP2 and DP1 as closely together as possible... same for the DMs
C2 and C48 may need to be swapped to get the passive oscillator working
12MHz Oscillator

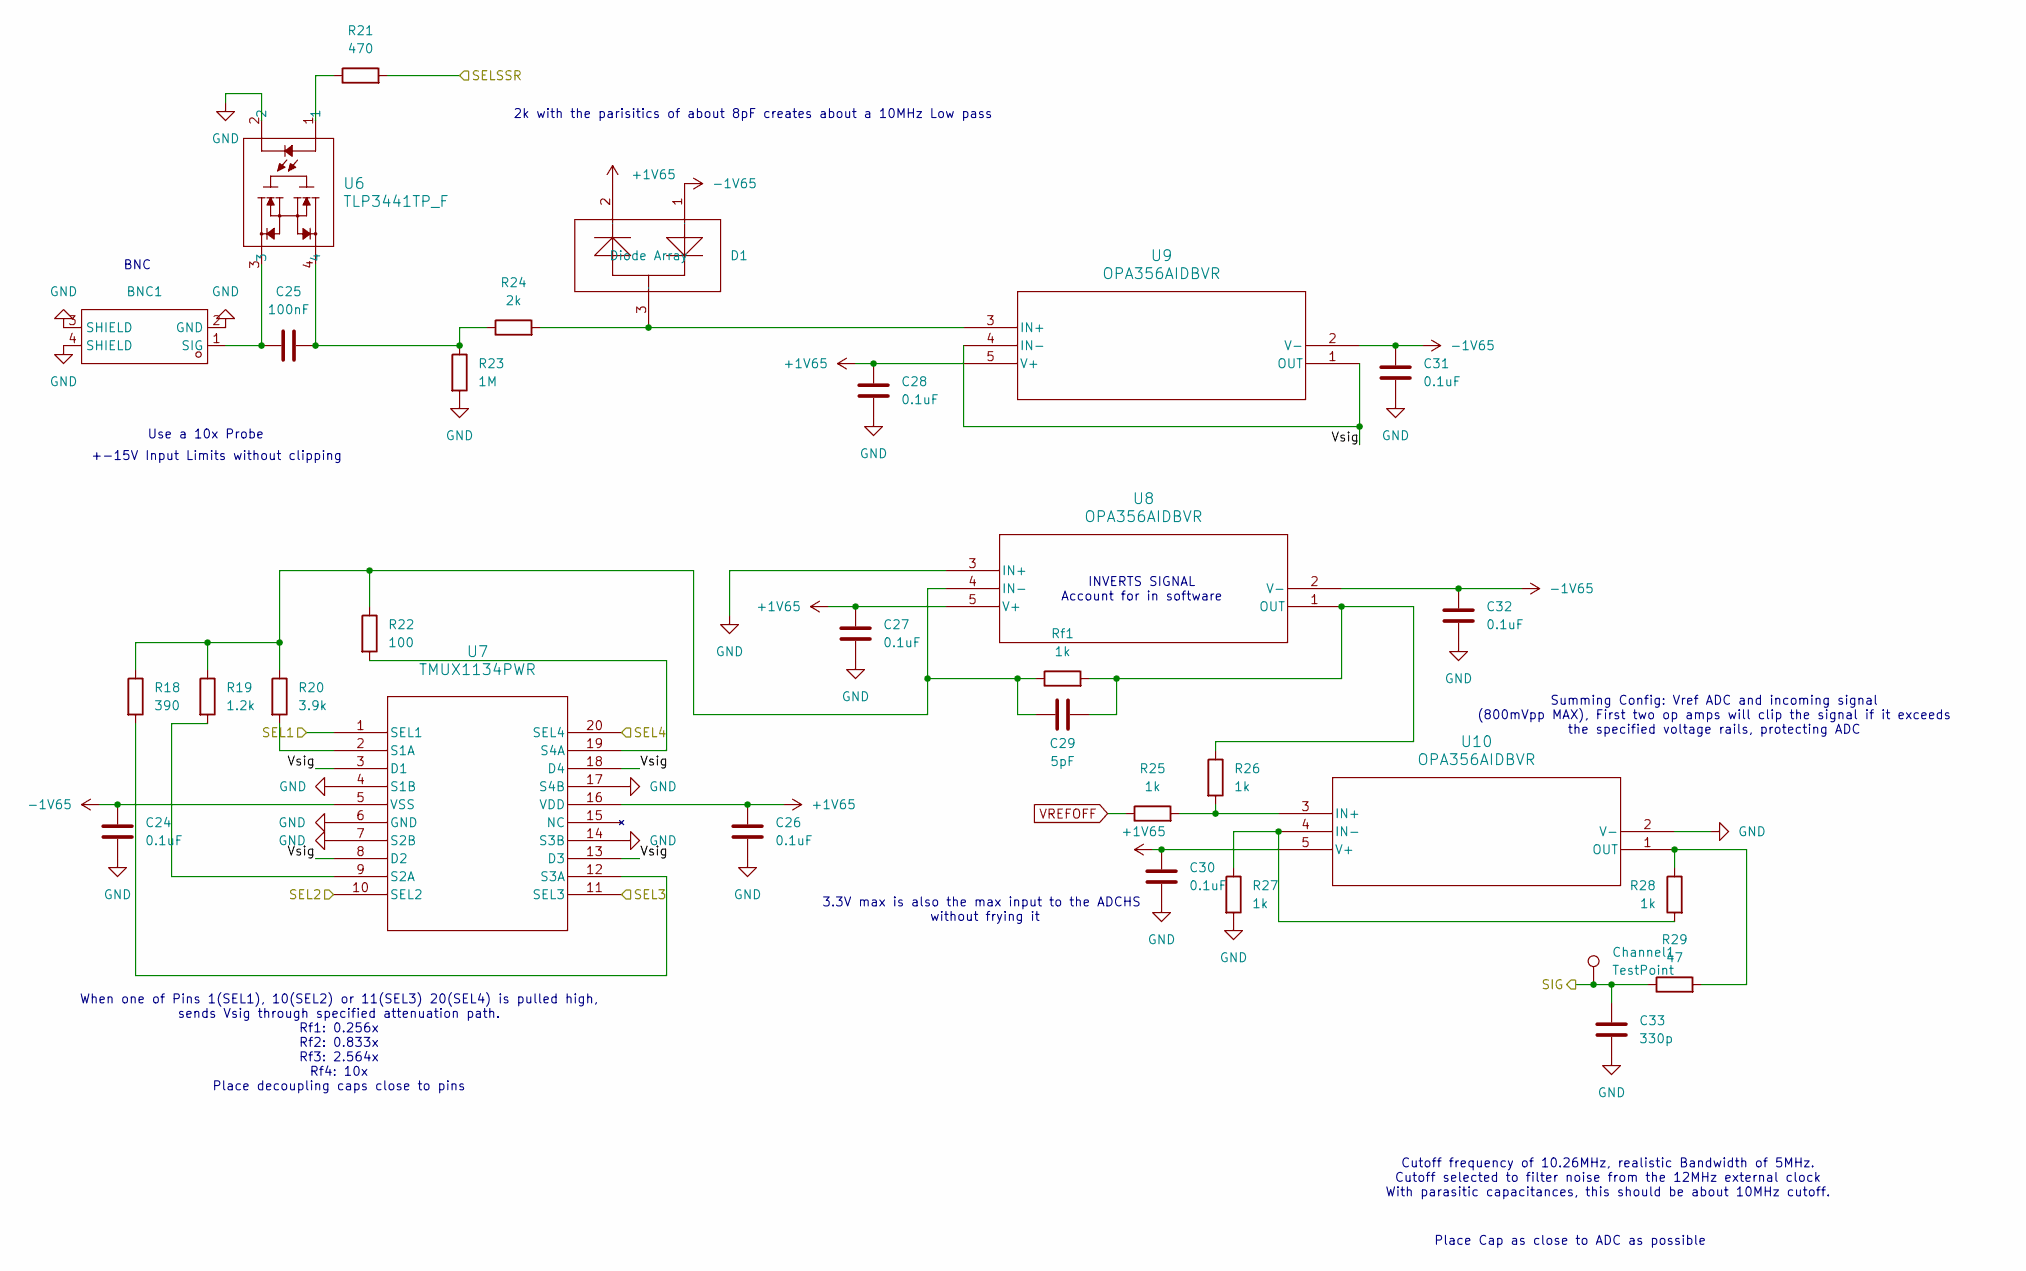
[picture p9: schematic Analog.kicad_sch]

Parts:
BNC1: 3GHz; BNC Connector 2.0; Manufacturer Part DOSIN-801-0038; LCSC Part Name 3件套 内孔 BNC 弯头
C24, C26, C27, C28, C30, C31, C32: 0.1uF; C_0402_1005Metric; Part type Basic
C25: 100nF; C_1206_3216Metric; Part type Extended
C29: 5pF; C_0603_1608Metric; Part type Extended
C33: 330p; C_0603_1608Metric; Part type Basic
Channel1: TestPoint; TestPoint_Pad_1.0x1.0mm
D1: Diode Array; SOT-23-3_L2.9-W1.6-P1.90-LS2.8-BR ESD; Manufacturer Part -- mixed values --; LCSC Part Name -- mixed values --
R18: 390; R_0603_1608Metric; Part type Basic
R19: 1.2k; R_0603_1608Metric; Part type Basic
R20: 3.9k; R_0603_1608Metric; Part type Basic
R21: 470; R_0603_1608Metric; Part type Basic
R22: 100; R_0603_1608Metric; Part type Basic
R23: 1M; R_1206_3216Metric; Part type Extended
R24: 2k; R_0805_2012Metric; Part type Basic
R25, R26, R27, R28: 1k; R_0603_1608Metric; Part type Basic
R29: 47; R_0603_1608Metric; Part type Basic
Rf1: 1k; R_0603_1608Metric; Part type Basic
U6: TLP3441TP_F; VSON-4_L1.5-W2.5-P0.80-BL-DCAC-SWITCH; Part type Extended
U7: TMUX1134PWR; TSSOP20_PW_TEX-MUX; Part type Extended
U8, U9, U10: OPA356AIDBVR; DBV5-OPAMP; Part type Extended

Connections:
+1V65: C26.1, C27.1, C28.1, C30.1, D1.2, U7.16 (VDD), U8.5 (V+), U9.5 (V+), U10.5 (V+); also elsewhere on the board
-1V65: C24.1, C31.1, C32.1, D1.1, U7.5 (VSS), U8.2 (V-), U9.2 (V-); also elsewhere on the board
/Analog1/Vsig: U7.3 (D1), U7.8 (D2), U7.13 (D3), U7.18 (D4), U9.1 (OUT), U9.4 (IN-)
/CH1_SEL1: U7.1 (SEL1); also elsewhere on the board
/CH1_SEL2: U7.10 (SEL2); also elsewhere on the board
/CH1_SEL3: U7.11 (SEL3); also elsewhere on the board
/CH1_SEL4: U7.20 (SEL4); also elsewhere on the board
/CH1_SELSSR: R21.2; also elsewhere on the board
/Channel1: C33.1, Channel1.1 (1_1), R29.1; also elsewhere on the board
GND: BNC1.2 (GND), BNC1.3 (SHIELD), BNC1.4 (SHIELD), C24.2, C26.2, C27.2, C28.2, C30.2, C31.2, C32.2, C33.2, R23.2, R27.2, U6.2, U7.4 (S1B), U7.6 (GND), U7.7 (S2B), U7.14 (S3B), U7.17 (S4B), U8.3 (IN+), U10.2 (V-); also elsewhere on the board
unnamed: BNC1.1 (SIG), C25.1, U6.3
unnamed: C25.2, R23.1, R24.1, U6.4
unnamed: R21.1, U6.1
unnamed: R20.2, U7.2 (S1A)
unnamed: R19.2, U7.9 (S2A)
unnamed: R18.2, U7.12 (S3A)
unnamed: R22.2, U7.19 (S4A)
unnamed: C29.2, R18.1, R19.1, R20.1, R22.1, Rf1.1, U8.4 (IN-)
unnamed: C29.1, R26.1, Rf1.2, U8.1 (OUT)
unnamed: D1.3, R24.2, U9.3 (IN+)
unnamed: R25.2, R26.2, U10.3 (IN+)
unnamed: R27.1, R28.2, U10.4 (IN-)
unnamed: R28.1, R29.2, U10.1 (OUT)
VREFOFF: R25.1; also elsewhere on the board

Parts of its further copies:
BNC2: 3GHz; BNC Connector 2.0; Manufacturer Part DOSIN-801-0038; LCSC Part Name 3件套 内孔 BNC 弯头
C34, C36, C37, C38, C40, C41, C42: 0.1uF; C_0402_1005Metric; Part type Basic
C35: 100nF; C_1206_3216Metric; Part type Extended
C39: 5pF; C_0603_1608Metric; Part type Extended
C43: 330p; C_0603_1608Metric; Part type Basic
D2: Diode Array; SOT-23-3_L2.9-W1.6-P1.90-LS2.8-BR ESD; Manufacturer Part -- mixed values --; LCSC Part Name -- mixed values --
R30: 390; R_0603_1608Metric; Part type Basic
R31: 1.2k; R_0603_1608Metric; Part type Basic
R32: 3.9k; R_0603_1608Metric; Part type Basic
R33: 470; R_0603_1608Metric; Part type Basic
R34: 100; R_0603_1608Metric; Part type Basic
R35: 1M; R_1206_3216Metric; Part type Extended
R36: 2k; R_0805_2012Metric; Part type Basic
R37, R38, R39, R40: 1k; R_0603_1608Metric; Part type Basic
R41: 47; R_0603_1608Metric; Part type Basic
Rf2: 1k; R_0603_1608Metric; Part type Basic
TP12: TestPoint; TestPoint_Pad_1.0x1.0mm
U11: TLP3441TP_F; VSON-4_L1.5-W2.5-P0.80-BL-DCAC-SWITCH; Part type Extended
U12: TMUX1134PWR; TSSOP20_PW_TEX-MUX; Part type Extended
U13, U14, U15: OPA356AIDBVR; DBV5-OPAMP; Part type Extended

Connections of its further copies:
+1V65: C36.1, C37.1, C38.1, C40.1, D2.2, U12.16 (VDD), U13.5 (V+), U14.5 (V+), U15.5 (V+); also elsewhere on the board
-1V65: C34.1, C41.1, C42.1, D2.1, U12.5 (VSS), U13.2 (V-), U14.2 (V-); also elsewhere on the board
/Analog2/Vsig: U12.3 (D1), U12.8 (D2), U12.13 (D3), U12.18 (D4), U14.1 (OUT), U14.4 (IN-)
/CH2_SEL1: U12.1 (SEL1); also elsewhere on the board
/CH2_SEL2: U12.10 (SEL2); also elsewhere on the board
/CH2_SEL3: U12.11 (SEL3); also elsewhere on the board
/CH2_SEL4: U12.20 (SEL4); also elsewhere on the board
/CH2_SELSSR: R33.2; also elsewhere on the board
/Channel2: C43.1, R41.1, TP12.1 (1_1); also elsewhere on the board
GND: BNC2.2 (GND), BNC2.3 (SHIELD), BNC2.4 (SHIELD), C34.2, C36.2, C37.2, C38.2, C40.2, C41.2, C42.2, C43.2, R35.2, R39.2, U11.2, U12.4 (S1B), U12.6 (GND), U12.7 (S2B), U12.14 (S3B), U12.17 (S4B), U13.3 (IN+), U15.2 (V-); also elsewhere on the board
unnamed: BNC2.1 (SIG), C35.1, U11.3
unnamed: C35.2, R35.1, R36.1, U11.4
unnamed: R33.1, U11.1
unnamed: R32.2, U12.2 (S1A)
unnamed: R31.2, U12.9 (S2A)
unnamed: R30.2, U12.12 (S3A)
unnamed: R34.2, U12.19 (S4A)
unnamed: C39.2, R30.1, R31.1, R32.1, R34.1, Rf2.1, U13.4 (IN-)
unnamed: C39.1, R38.1, Rf2.2, U13.1 (OUT)
unnamed: D2.3, R36.2, U14.3 (IN+)
unnamed: R37.2, R38.2, U15.3 (IN+)
unnamed: R39.1, R40.2, U15.4 (IN-)
unnamed: R40.1, R41.2, U15.1 (OUT)
VREFOFF: R37.1; also elsewhere on the board

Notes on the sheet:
2k with the parisitics of about 8pF creates about a 10MHz Low pass
When one of Pins 1(SEL1), 10(SEL2) or 11(SEL3) 20(SEL4) is pulled high, sends Vsig through specified attenuation path. Rf1: 0.256x Rf2: 0.833x Rf3: 2.564x Rf4: 10x Place decoupling caps close to pins
3.3V max is also the max input to the ADCHS without frying it
Place Cap as close to ADC as possible
Cutoff frequency of 10.26MHz, realistic Bandwidth of 5MHz. Cutoff selected to filter noise from the 12MHz external clock With parasitic capacitances, this should be about 10MHz cutoff.
+-15V Input Limits without clipping
BNC
Summing Config: Vref ADC and incoming signal (800mVpp MAX), First two op amps will clip the signal if it exceeds the specified voltage rails, protecting ADC
INVERTS SIGNAL Account for in software
Use a 10x Probe

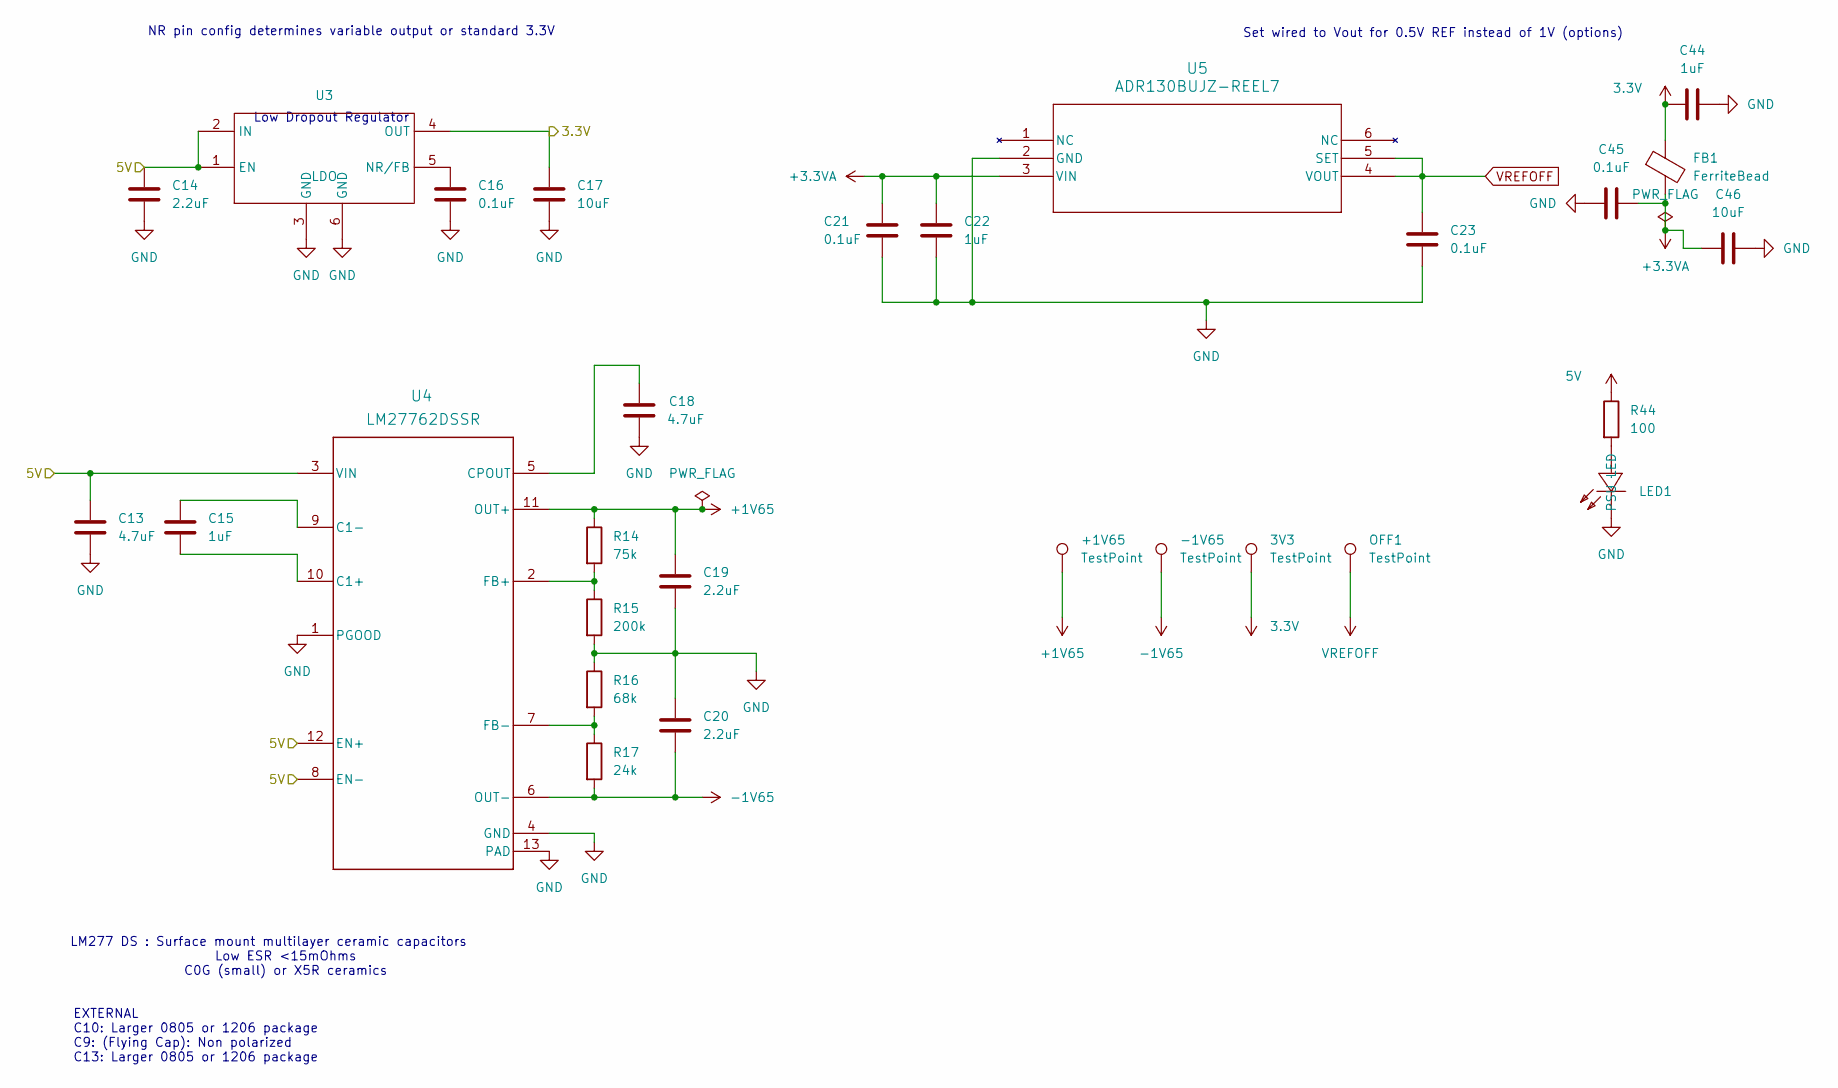
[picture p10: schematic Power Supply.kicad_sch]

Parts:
3V3: TestPoint; TestPoint_Pad_1.0x1.0mm
+1V65: TestPoint; TestPoint_Pad_1.0x1.0mm
-1V65: TestPoint; TestPoint_Pad_1.0x1.0mm
C13, C18: 4.7uF; C_0603_1608Metric; Part type Basic
C14, C19, C20: 2.2uF; C_0603_1608Metric; Part type Basic
C15, C22, C44: 1uF; C_0603_1608Metric; Part type Basic
C16, C21, C23, C45: 0.1uF; C_0402_1005Metric; Part type Basic
C17, C46: 10uF; C_0603_1608Metric; Part type Basic
FB1: FerriteBead; L0603 (Ferrite Bead); Part type Basic
LED1: PSU LED; Manufacturer Part KT-0603W; LCSC Part Name 0603 红灯 高亮
OFF1: TestPoint; TestPoint_Pad_1.0x1.0mm
R14: 75k; R_0603_1608Metric; Part type Basic
R15: 200k; R_0603_1608Metric; Part type Basic
R16: 68k; R_0603_1608Metric; Part type Basic
R17: 24k; R_0603_1608Metric; Part type Basic
R44: 100; R_0603_1608Metric; Part type Basic
U3: LDO; SOT-223-6_L6.5-W3.5-P1.27-BL (LDO2.0); Manufacturer Part TPS79501DCQR; LCSC Part Name 具有使能功能的 500mA、低压降稳压器
U4: LM27762DSSR; WSON-12_L3.0-W2.0-P0.50-BL-EP (Charge Pump); Part type Extended
U5: ADR130BUJZ-REEL7; UJ_6_ADI; Part type Extended

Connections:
3.3V: 3V3.1 (1_1), C17.2, C44.1, FB1.1, U3.4 (OUT); also elsewhere on the board
5V: C13.2, C14.2, R44.1, U3.1 (EN), U3.2 (IN), U4.3 (VIN), U4.8 (EN-), U4.12 (EN+); also elsewhere on the board
+1V65: +1V65.1 (1_1), C19.2, R14.1, U4.11 (OUT+); also elsewhere on the board
+3.3VA: C21.2, C22.2, C45.1, C46.1, FB1.2, U5.3 (VIN)
-1V65: -1V65.1 (1_1), C20.1, R17.2, U4.6 (OUT-); also elsewhere on the board
GND: C13.1, C14.1, C16.1, C17.1, C18.1, C19.1, C20.2, C21.1, C22.1, C23.1, C44.2, C45.2, C46.2, LED1.1 (K), R15.2, R16.1, U3.3 (GND), U3.6 (GND), U4.1 (PGOOD), U4.4 (GND), U4.13 (PAD), U5.2 (GND); also elsewhere on the board
unnamed: LED1.2 (A), R44.2
unnamed: C16.2, U3.5 (NR/FB)
unnamed: C15.1, U4.10 (C1+)
unnamed: C15.2, U4.9 (C1-)
unnamed: C18.2, U4.5 (CPOUT)
unnamed: R14.2, R15.1, U4.2 (FB+)
unnamed: R16.2, R17.1, U4.7 (FB-)
VREFOFF: C23.2, OFF1.1 (1_1), U5.4 (VOUT), U5.5 (SET); also elsewhere on the board

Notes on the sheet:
LM277 DS : Surface mount multilayer ceramic capacitors Low ESR <15mOhms C0G (small) or X5R ceramics
Set wired to Vout for 0.5V REF instead of 1V (options)
Low Dropout Regulator
NR pin config determines variable output or standard 3.3V
EXTERNAL C10: Larger 0805 or 1206 package C9: (Flying Cap): Non polarized C13: Larger 0805 or 1206 package

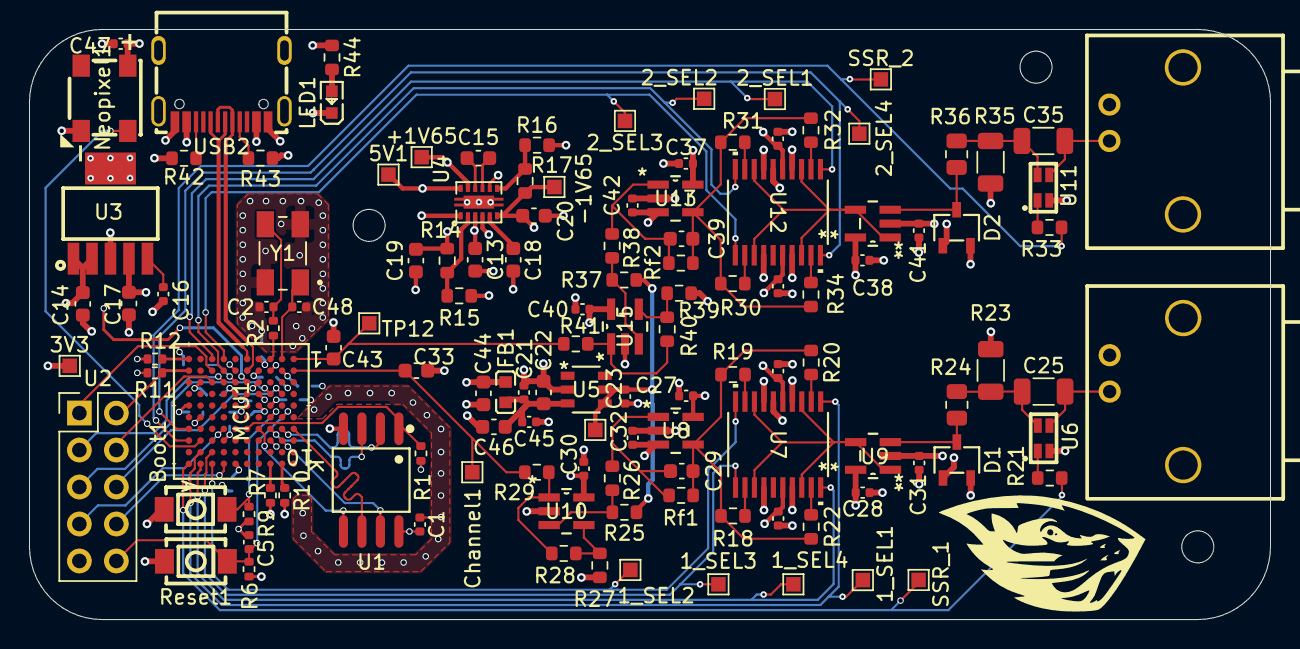
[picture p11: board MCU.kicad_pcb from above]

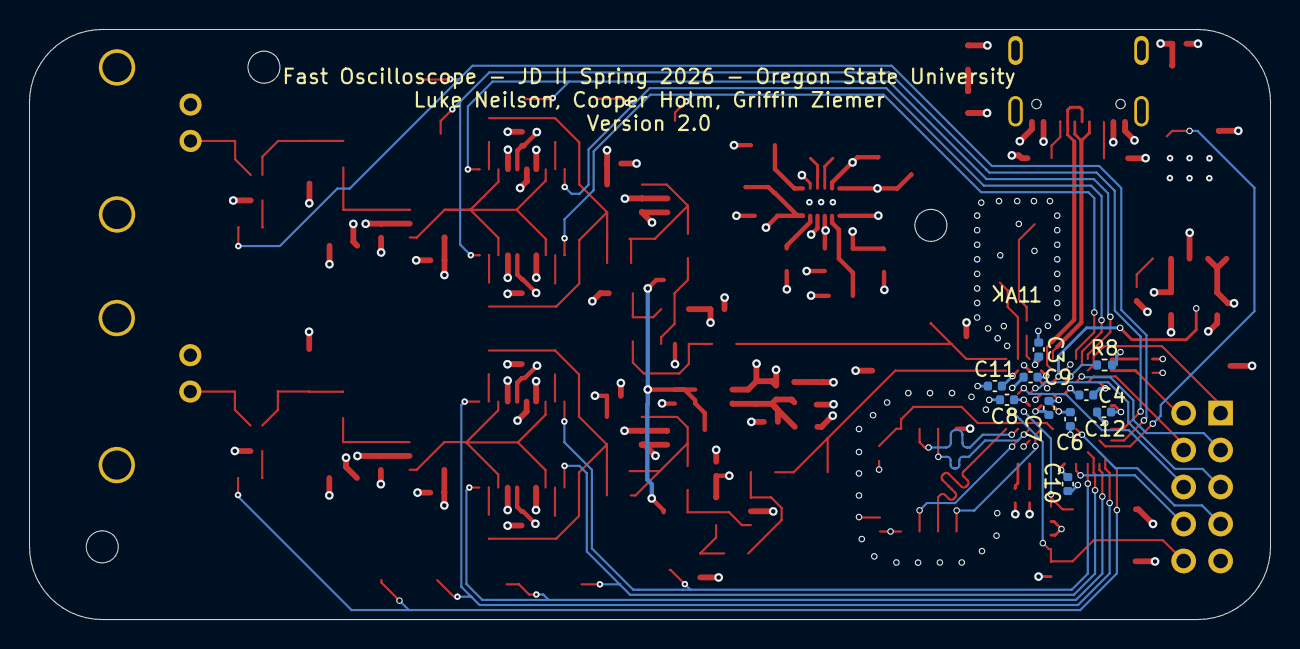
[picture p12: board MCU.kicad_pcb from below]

Board: 4 copper layers, 85.3 x 40.5 mm, 137 parts (10 on the bottom side), 82 nets.

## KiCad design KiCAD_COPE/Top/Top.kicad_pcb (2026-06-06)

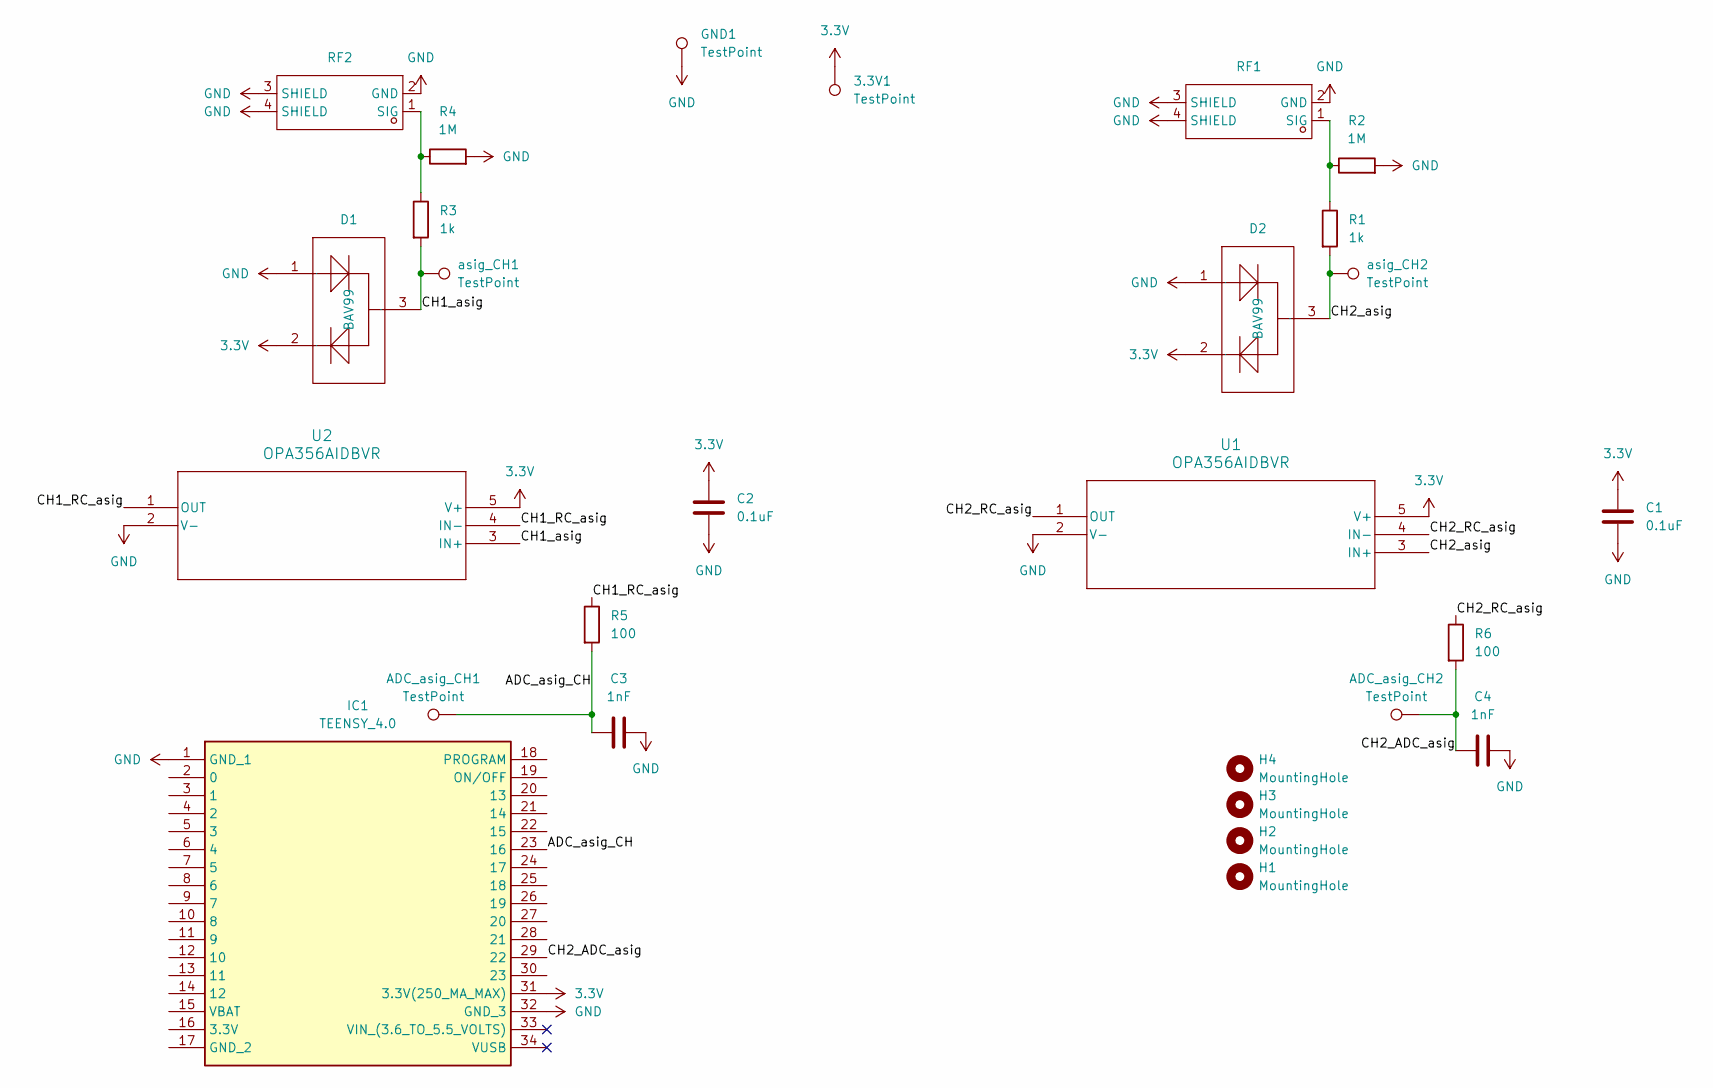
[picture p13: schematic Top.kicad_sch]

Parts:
3.3V1: TestPoint; TestPoint_Pad_1.0x1.0mm
ADC_asig_CH1, ADC_asig_CH2: TestPoint; TestPoint_Pad_1.0x1.0mm
C1, C2: 0.1uF; C_0402_1005Metric
C3, C4: 1nF; C_0402_1005Metric
D1, D2: BAV99; SOT-23-3_L2.9-W1.6-P1.90-LS2.8-BR-ESD; Manufacturer Part BAV99,215; LCSC Part Name 100V 215mA
GND1: TestPoint; TestPoint_Pad_1.0x1.0mm
H1, H2, H3, H4: MountingHole; MountingHole_2.2mm_M2
IC1: TEENSY_4.0; TEENSY4.0; Manufacturer_Part_Number TEENSY 4.0
R1, R3: 1k; R_0402_1005Metric
R2, R4: 1M; R_0402_1005Metric
R5, R6: 100; R_0402_1005Metric
RF1, RF2: BNC; BNC Connector 2.0; Manufacturer Part DOSIN-801-0038; LCSC Part Name 3件套 内孔 BNC 弯头
U1, U2: OPA356AIDBVR; DBV5-OPAMP
asig_CH1, asig_CH2: TestPoint; TestPoint_Pad_1.0x1.0mm

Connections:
3.3V: 3.3V1.1 (1_1), C1.1, C2.1, D1.2, D2.2, IC1.31 (3.3V(250_MA_MAX)), U1.5 (V+), U2.5 (V+)
/ADC_asig_CH: ADC_asig_CH1.1 (1_1), C3.1, IC1.23 (16), R5.2
/CH1_RC_asig: R5.1, U2.1 (OUT), U2.4 (IN-)
/CH1_asig: D1.3, R3.2, U2.3 (IN+), asig_CH1.1 (1_1)
/CH2_ADC_asig: ADC_asig_CH2.1 (1_1), C4.1, IC1.29 (22), R6.2
/CH2_RC_asig: R6.1, U1.1 (OUT), U1.4 (IN-)
/CH2_asig: D2.3, R1.2, U1.3 (IN+), asig_CH2.1 (1_1)
GND: C1.2, C2.2, C3.2, C4.2, D1.1, D2.1, GND1.1 (1_1), IC1.1 (GND_1), IC1.32 (GND_3), R2.2, R4.2, RF1.2 (GND), RF1.3 (SHIELD), RF1.4 (SHIELD), RF2.2 (GND), RF2.3 (SHIELD), RF2.4 (SHIELD), U1.2 (V-), U2.2 (V-)
unnamed: R1.1, R2.1, RF1.1 (SIG)
unnamed: R3.1, R4.1, RF2.1 (SIG)

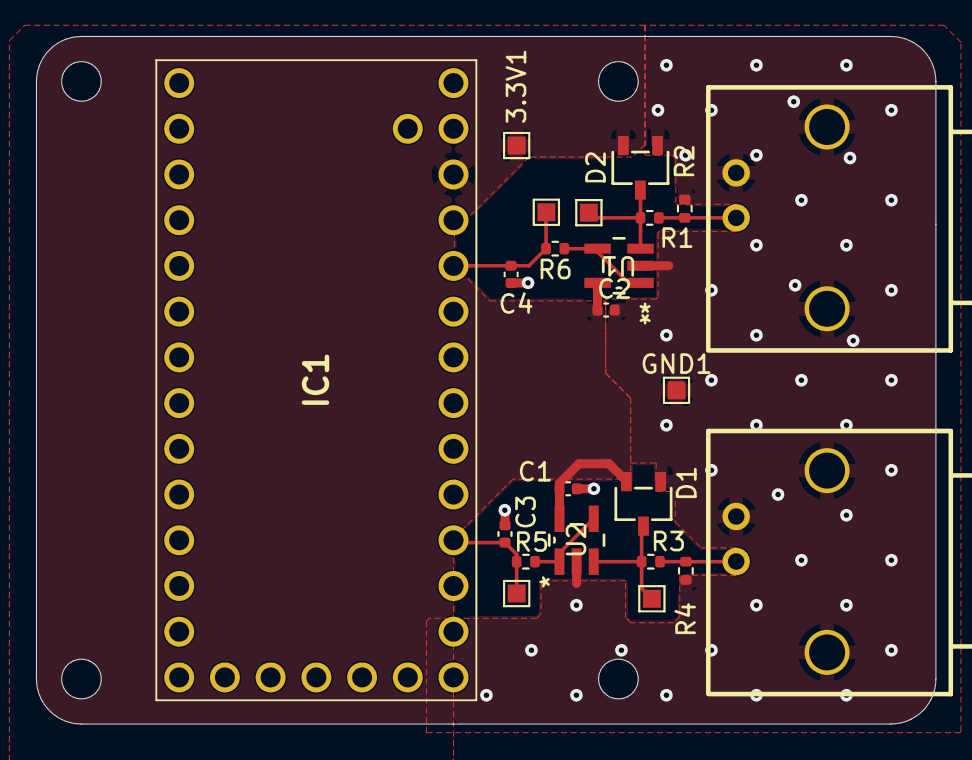
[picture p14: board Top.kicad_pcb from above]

Board: 2 copper layers, 50.0 x 38.2 mm, 27 parts (0 on the bottom side), 10 nets.

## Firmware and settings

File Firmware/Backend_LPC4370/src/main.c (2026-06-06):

/*
 * main.c - FastOscilloscope LPC4370 firmware entry.
 *
 * Superloop architecture (no RTOS):
 *
 *   while (1) {
 *       usb_cdc_task();                   // pump USB stack
 *       drain_rx_and_dispatch();          // parse incoming command bytes
 *       if (acquiring) maybe_send_block(); // ship completed ADC bursts
 *   }
 *
 * Two interrupt sources:
 *   - USB IRQ: filled by nxpUSBlib's usbd_rom driver (handled inside vcom_*)
 *   - DMA IRQ: ADCHS burst-complete; sets the ready flag in adchs.c
 *
 * Scaling and trigger arithmetic stays on the host (host_bridge.py /
 * Display block) - the firmware just bursts raw 12-bit samples. This
 * matches the Block 2 design doc's pipeline ("Backend converts ADC
 * counts to voltage").
 */

#include "adchs.h"
#include "afe.h"
#include "clock.h"
#include "proto.h"
#include "usb_cdc.h"

#include "chip.h"

#include <stdbool.h>
#include <stdint.h>
#include <string.h>

/* ---- runtime state ---- */

static bool s_acquiring     = false;
static bool s_single_pending = false;

/* Trigger state - cached across the 3 individual SET_TRIGGER_* commands
 * so we always have a coherent (source, level, mode) triple to push down
 * to adchs_set_trigger().                                              */
static uint8_t s_trig_source = 1;
static int32_t s_trig_level  = 0;
static uint8_t s_trig_mode   = 0;  /* 0=rising, 1=falling, 2=auto */

static uint8_t  s_pkt_scratch[5 + 2 * ADCHS_BLOCK_SAMPLES];
static uint16_t s_sample_scratch[ADCHS_BLOCK_SAMPLES];

/* ---- helpers ---- */

static uint32_t be_u32(const uint8_t *p)
{
    return ((uint32_t)p[0] << 24) | ((uint32_t)p[1] << 16) |
           ((uint32_t)p[2] << 8)  |  (uint32_t)p[3];
}
static int32_t  be_i32(const uint8_t *p) { return (int32_t)be_u32(p); }

/* ---- command dispatch ---- */

static void handle_command(const proto_cmd_t *cmd)
{
    switch (cmd->id) {

    case PROTO_CMD_SET_TIMEBASE: {
        /* uint32 ns/div from the host. We want one ADCHS_BLOCK_SAMPLES-sample
         * block to cover (10 divs × ns_per_div) of time, so:
         *   sample_rate   = SAMPLES / (10 × ns_per_div × 1e-9)
         *                 = SAMPLES × 1e8 / ns_per_div   [Hz]
         *   ADCHS divider = ADCHS_BASE_CLOCK_HZ / sample_rate
         *                 = ADCHS_BASE_CLOCK_HZ × ns_per_div / (SAMPLES × 1e8)
         * (SAMPLES × 1e8 is derived from ADCHS_BLOCK_SAMPLES so depth + this
         *  math can never drift apart.) Clamped to [1, 65535]. The host applies
         *  the identical formula for its time axis, so it stays accurate even
         *  when the divider clamps at fast timebases. */
        uint32_t ns_per_div = be_u32(cmd->payload);
        if (ns_per_div == 0) break;
        uint64_t denom = (uint64_t)ADCHS_BLOCK_SAMPLES * 100000000ULL;
        uint64_t div = ((uint64_t)ADCHS_BASE_CLOCK_HZ * ns_per_div) / denom;
        if (div < 1)     div = 1;
        if (div > 65535) div = 65535;
        adchs_set_sample_rate_divider((uint16_t)div);
        break;
    }

    case PROTO_CMD_SET_VDIV: {
        /* Payload is uV per division. We turn that requested vertical scale
         * into one of the four AFE gain cells: a small V/div means the user is
         * looking at a tiny signal, so we want the biggest gain to fill the
         * ADC range, and a large V/div wants the smallest gain so a big signal
         * does not clip. The thresholds below are the crossover points between
         * the 10x, 2.564x, 0.833x, and 0.256x cells.
         *
         * Note this drives BOTH channels to the same gain. There is no per
         * channel gain command yet; if you need independent gain, see the
         * variable gain notes in afe.c and the README. */
        uint32_t uv_per_div = be_u32(cmd->payload);
        afe_gain_t g;
        if      (uv_per_div <  100000) g = AFE_GAIN_10_0;     /* below 0.1 V/div */
        else if (uv_per_div <  500000) g = AFE_GAIN_2_564;
        else if (uv_per_div < 2000000) g = AFE_GAIN_0_833;
        else                           g = AFE_GAIN_0_256;
        afe_set_gain(1, g);
        afe_set_gain(2, g);
        break;
    }

    /* When the AC/DC coupling switch gets wired up, its command handler goes
     * right here next to the other AFE control, for example:
     *   case PROTO_CMD_SET_COUPLING:
     *       afe_set_coupling_dc(cmd->payload[0], cmd->payload[1]);
     *       break;
     * The driver afe_set_coupling_dc() already exists; this case plus the
     * matching proto.h ID and host_bridge.py entry are all that is missing. */

    case PROTO_CMD_SET_VOFFSET:
        /* int32 µV - analog offset is fixed in this AFE; no-op for now. */
        (void)be_i32(cmd->payload);
        break;

    case PROTO_CMD_SET_TRIGGER_LEVEL:
        s_trig_level = be_i32(cmd->payload);
        adchs_set_trigger(s_trig_source, s_trig_level, s_trig_mode);
        break;

    case PROTO_CMD_SET_TRIGGER_MODE:
        /* payload[0]: 0=rising, 1=falling, 2=auto (matches ADCHS_TRIG_*) */
        s_trig_mode = cmd->payload[0];
        adchs_set_trigger(s_trig_source, s_trig_level, s_trig_mode);
        break;

    case PROTO_CMD_SET_TRIGGER_SOURCE:
#ifdef DMA_DEBUG_SWEEP
        /* DIAGNOSTIC: hijack this command to re-point the HSADC input (0-5) so
         * the host can sweep all inputs and find which one carries the signal. */
        {
            extern void adchs_debug_set_input(uint8_t);
            adchs_debug_set_input(cmd->payload[0]);
        }
        break;
#else
        /* payload[0]: 1=Ch1, 2=Ch2 */
        s_trig_source = (cmd->payload[0] == 2) ? 2 : 1;
        adchs_set_trigger(s_trig_source, s_trig_level, s_trig_mode);
        break;
#endif

    case PROTO_CMD_SET_CHANNEL: {
        /* payload[0] = channel (1 or 2), payload[1] = enabled (0/1) */
        uint8_t ch = cmd->payload[0];
        bool    on = cmd->payload[1] != 0;
        adchs_set_channel_enabled(ch, on);
        break;
    }

    case PROTO_CMD_RUN:
        if (!s_acquiring) {
            s_acquiring = true;
            adchs_start_capture();
        }
        break;

    case PROTO_CMD_STOP:
        if (s_acquiring) {
            adchs_stop_capture();
            s_acquiring = false;
        }
        break;

    case PROTO_CMD_SINGLE:
        s_single_pending = true;
        if (!s_acquiring) {
            s_acquiring = true;
            adchs_start_capture();
        }
        break;
    }
}

static void drain_rx_and_dispatch(void)
{
    uint8_t buf[64];
    uint16_t n = usb_cdc_read(buf, sizeof(buf));
    proto_cmd_t cmd;
    for (uint16_t i = 0; i < n; i++) {
        if (proto_parse_byte(buf[i], &cmd)) {
            handle_command(&cmd);
        }
    }
}

/* Throttle outgoing ADC blocks to ~30/s. The polled capture can fill blocks
 * far faster than USB-CDC (~1 MB/s) can carry them; streaming unthrottled
 * floods the link and corrupts packets. 30 blocks/s is plenty for a display
 * refresh and stays well inside the CDC budget. Uses the DWT cycle counter
 * (enabled in main()). */
static uint32_t s_last_block_cyc = 0;

static void maybe_send_block(void)
{
#ifdef DMA_DEBUG
    /* Diagnostic build: stream the GPDMA/HSADC register snapshot CONTINUOUSLY
     * from boot - independent of s_acquiring and adchs_start_capture(). This
     * lets us tell whether the USB/streaming path works on its own. The capture
     * is (optionally) kicked once at boot via DMA_DEBUG_BOOT_CAPTURE in main(). */
    if ((DWT->CYCCNT - s_last_block_cyc) < (SystemCoreClock / 30u)) return;
    s_last_block_cyc = DWT->CYCCNT;
    {
        extern void adchs_get_debug(uint16_t *, int);
        uint16_t dbg[27];
        adchs_get_debug(dbg, 27);
        uint16_t db = proto_build_data_packet(s_pkt_scratch, sizeof(s_pkt_scratch),
                                              PROTO_DATA_TYPE_CH1, dbg, 27);
        uint16_t sent = (db > 0) ? usb_cdc_write(s_pkt_scratch, db) : 0;
#ifdef DMA_DEBUG_DELAYED_CAPTURE
        /* Bisect: kick the capture ONCE, but only AFTER the host has actually
         * received ~20 frames (writes succeed only when a host is draining the
         * endpoint). This guarantees a listener is connected and watching when
         * capture fires, so it sees the pre/post transition. If the stream dies
         * right after, adchs_start_capture() is what wedges USB. */
        {
            static uint32_t s_dbg_sent = 0;
            if (sent > 0 && ++s_dbg_sent == 20) {
                adchs_start_capture();
            }
        }
#else
        (void) sent;
#endif
    }
    return;
#else
    if (!s_acquiring) return;

    if ((DWT->CYCCNT - s_last_block_cyc) < (SystemCoreClock / 30u)) return;
    s_last_block_cyc = DWT->CYCCNT;

    if (adchs_block_ready(1)) {
        uint16_t count = adchs_get_block(1, s_sample_scratch);
        uint16_t bytes = proto_build_data_packet(
            s_pkt_scratch, sizeof(s_pkt_scratch),
            PROTO_DATA_TYPE_CH1, s_sample_scratch, count);
        if (bytes > 0) {
            usb_cdc_write(s_pkt_scratch, bytes);
        }
    }

    if (adchs_block_ready(2)) {
        uint16_t count = adchs_get_block(2, s_sample_scratch);
        uint16_t bytes = proto_build_data_packet(
            s_pkt_scratch, sizeof(s_pkt_scratch),
            PROTO_DATA_TYPE_CH2, s_sample_scratch, count);
        if (bytes > 0) {
            usb_cdc_write(s_pkt_scratch, bytes);
        }

        if (s_single_pending) {
            s_single_pending = false;
            adchs_stop_capture();
            s_acquiring = false;
        }
    }
#endif /* DMA_DEBUG */
}

/* ---- DMA IRQ glue ---- */
extern void adchs_dma_complete_isr(uint8_t dma_channel);

void DMA_IRQHandler(void)
{
    /* GPDMA terminal-count + error handling. */
    uint8_t tc = Chip_GPDMA_IntGetStatus(LPC_GPDMA, GPDMA_STAT_INTTC, 0);
    if (tc) { adchs_dma_complete_isr(0); Chip_GPDMA_ClearIntPending(LPC_GPDMA, GPDMA_STATCLR_INTTC, 0); }

    tc = Chip_GPDMA_IntGetStatus(LPC_GPDMA, GPDMA_STAT_INTTC, 1);
    if (tc) { adchs_dma_complete_isr(1); Chip_GPDMA_ClearIntPending(LPC_GPDMA, GPDMA_STATCLR_INTTC, 1); }

    /* Swallow errors - the bad block is dropped, capture continues. */
    for (uint8_t ch = 0; ch < 2; ch++) {
        if (Chip_GPDMA_IntGetStatus(LPC_GPDMA, GPDMA_STAT_INTERR, ch)) {
            Chip_GPDMA_ClearIntPending(LPC_GPDMA, GPDMA_STATCLR_INTERR, ch);
        }
    }
}

/* ---- entry ---- */

#ifdef MILESTONE1_BLINK
/* TEMPORARY bring-up hook (Milestone 1): visible WS2812 blink that never
 * returns. Defined in milestone1_blink.c, compiled in only for the blink
 * build. Remove once USB bring-up (Milestone 2+) is underway. */
extern void milestone1_blink_forever(void);
#endif

int main(void)
{
    SystemCoreClockUpdate();
    clock_init();

#ifdef MILESTONE1_BLINK
    milestone1_blink_forever();   /* proves toolchain+flash+clock; loops forever */
#endif

    /* GPIO clock + AFE pin setup. */
    Chip_GPIO_Init(LPC_GPIO_PORT);
#ifndef MILESTONE2_USB_ONLY
    afe_init();

    /* ADCHS + DMA bring-up (idle until first RUN). */
    adchs_init();
#endif

    /* USB CDC bring-up; blocks until host enumerates the COM port. */
    usb_cdc_init();

    /* USB is up, so PLL0USB (480 MHz) now exists - bump the ADC sample clock
     * from the 68 MHz default to 80 MHz (480/6). Harmless if the ADC is unused. */
#ifndef ADCHS_CLOCK_68MHZ   /* define to stay at the 68 MHz clock_init default */
    clock_set_adchs_80mhz();
#endif

    /* Enable the DWT cycle counter - used by maybe_send_block() to throttle. */
    CoreDebug->DEMCR |= CoreDebug_DEMCR_TRCENA_Msk;
    DWT->CYCCNT = 0;
    DWT->CTRL  |= DWT_CTRL_CYCCNTENA_Msk;

#ifdef DMA_DEBUG_BOOT_CAPTURE
    /* Bisect hook: kick the HSADC capture once here, so the DMA_DEBUG stream
     * shows live FIFO/DSCR/DMA progress without depending on a host RUN. If the
     * USB dies right after this, the fault is inside adchs_start_capture(). */
    adchs_start_capture();
#endif

    /* Superloop. */
    while (1) {
        usb_cdc_task();
        drain_rx_and_dispatch();
        maybe_send_block();
    }

    /* Unreachable. */
    return 0;
}

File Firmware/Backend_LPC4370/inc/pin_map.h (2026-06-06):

/*
 * pin_map.h
 *
 * Named pin defines for the FastOscilloscope LPC4370 board. All values
 * come from the Luke's pin-assignment table (Pin Changes, rev. June 2026).
 *
 * The LPC4370 multiplexes I/O via the System Control Unit (SCU). Each
 * physical pin (e.g. P1_18) selects a function (FUNC0..FUNC7) that maps
 * it to a peripheral. To use a pin as a GPIO we also need to know which
 * GPIO port/bit it lands on after the SCU mapping; the LPC43xx user
 * manual Table 158 lists those.
 *
 * Format used below for GPIO outputs:
 *   <NAME>_PORT, <NAME>_BIT, <NAME>_SCU_PORT, <NAME>_SCU_PIN, <NAME>_SCU_FUNC
 *
 * The SCU_FUNC is whichever FUNC# routes the physical pin to a normal
 * GPIO pad (most LPC43xx pins use FUNC0 or FUNC4 for GPIO).
 */

#ifndef _PIN_MAP_H_
#define _PIN_MAP_H_

/* ----- Channel 1 AFE: gain switch (one-hot) ------------------------- */
/* CH1_SEL1 -> 0.256x   P6_2   -> GPIO3[1]   (FUNC0) */
#define CH1_SEL1_PORT      3
#define CH1_SEL1_BIT       1
#define CH1_SEL1_SCU_PORT  6
#define CH1_SEL1_SCU_PIN   2
#define CH1_SEL1_SCU_FUNC  0

/* CH1_SEL2 -> 0.833x   P1_17  -> GPIO0[12]  (FUNC0) */
#define CH1_SEL2_PORT      0
#define CH1_SEL2_BIT       12
#define CH1_SEL2_SCU_PORT  1
#define CH1_SEL2_SCU_PIN   17
#define CH1_SEL2_SCU_FUNC  0

/* CH1_SEL3 -> 2.564x   P1_16  -> GPIO0[3]   (FUNC0) */
#define CH1_SEL3_PORT      0
#define CH1_SEL3_BIT       3
#define CH1_SEL3_SCU_PORT  1
#define CH1_SEL3_SCU_PIN   16
#define CH1_SEL3_SCU_FUNC  0

/* CH1_SEL4 -> 10x      P1_18  -> GPIO0[13]  (FUNC0) */
#define CH1_SEL4_PORT      0
#define CH1_SEL4_BIT       13
#define CH1_SEL4_SCU_PORT  1
#define CH1_SEL4_SCU_PIN   18
#define CH1_SEL4_SCU_FUNC  0

/* CH1_SELSSR (DC=high, AC=low)   P1_20 -> GPIO0[15] (FUNC0) */
#define CH1_SELSSR_PORT      0
#define CH1_SELSSR_BIT       15
#define CH1_SELSSR_SCU_PORT  1
#define CH1_SELSSR_SCU_PIN   20
#define CH1_SELSSR_SCU_FUNC  0

/* ----- Channel 2 AFE: gain switch (one-hot) ------------------------- */
/* CH2_SEL1 -> 0.256x   P1_0   -> GPIO0[4]   (FUNC0) */
#define CH2_SEL1_PORT      0
#define CH2_SEL1_BIT       4
#define CH2_SEL1_SCU_PORT  1
#define CH2_SEL1_SCU_PIN   0
#define CH2_SEL1_SCU_FUNC  0

/* CH2_SEL2 -> 0.833x   P0_0   -> GPIO0[0]   (FUNC0) */
#define CH2_SEL2_PORT      0
#define CH2_SEL2_BIT       0
#define CH2_SEL2_SCU_PORT  0
#define CH2_SEL2_SCU_PIN   0
#define CH2_SEL2_SCU_FUNC  0

/* CH2_SEL3 -> 2.564x   P0_1   -> GPIO0[1]   (FUNC0) */
#define CH2_SEL3_PORT      0
#define CH2_SEL3_BIT       1
#define CH2_SEL3_SCU_PORT  0
#define CH2_SEL3_SCU_PIN   1
#define CH2_SEL3_SCU_FUNC  0

/* CH2_SEL4 -> 10x      P1_12  -> GPIO1[5]   (FUNC0) */
#define CH2_SEL4_PORT      1
#define CH2_SEL4_BIT       5
#define CH2_SEL4_SCU_PORT  1
#define CH2_SEL4_SCU_PIN   12
#define CH2_SEL4_SCU_FUNC  0

/* CH2_SELSSR (DC=high, AC=low)   P1_15 -> GPIO0[2]  (FUNC0) */
#define CH2_SELSSR_PORT      0
#define CH2_SELSSR_BIT       2
#define CH2_SELSSR_SCU_PORT  1
#define CH2_SELSSR_SCU_PIN   15
#define CH2_SELSSR_SCU_FUNC  0

/* ----- ADCHS analog inputs ----------------------------------------- */
/* ADCHS_0 = Channel 2 input (board net "Channel2") */
/* ADCHS_1 = Channel 1 input (board net "Channel1") */
#define ADCHS_CHANNEL_FOR_CH1   1   /* Ch1 PCB net  -> ADCHS input 1 */
#define ADCHS_CHANNEL_FOR_CH2   0   /* Ch2 PCB net  -> ADCHS input 0 */

/* ----- Misc -------------------------------------------------------- */
/* Neopixel data line                P1_14 -> GPIO1[7]  (FUNC0) */
#define NEOPIXEL_PORT      1
#define NEOPIXEL_BIT       7
#define NEOPIXEL_SCU_PORT  1
#define NEOPIXEL_SCU_PIN   14
#define NEOPIXEL_SCU_FUNC  0

#endif /* _PIN_MAP_H_ */

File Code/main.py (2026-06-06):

"""FastOscilloscope main window.

Plot area on the left, UserInputPanelQt on the right. The control panel
emits command dicts; they go (a) to a local handler that updates display
state and (b) into the Backend which packetizes them onto the USB serial
link to the MCU. The Backend's worker thread parses incoming ADC blocks,
converts counts -> volts, and pushes records back through the main-thread
pump for plotting.

Without a MCU connected, a MockMCU stands in for the hardware so the demo
runs end-to-end on any laptop.
"""

import sys
import time
from typing import Optional

import numpy as np
import pyqtgraph as pg
from PyQt5.QtWidgets import (
    QApplication, QMainWindow, QVBoxLayout, QHBoxLayout, QWidget, QLabel,
)
from PyQt5.QtCore import QTimer

from host_bridge import (HostBridge, SAMPLES_PER_BLOCK, ADCHS_BASE_CLOCK_HZ,
                         ADC_MAX, V_REF, AFE_GAIN)
from mock_mcu import MockMCU
from user_input_qt import UserInputPanelQt


class OscilloscopeUI(QMainWindow):

    # Standard scope: 10 horizontal divs, 10 vertical divs.
    H_DIVS = 10
    V_DIVS = 10

    def __init__(self, port: Optional[str] = None):
        super().__init__()
        self.setWindowTitle("FastOscilloscope - LPC4370")
        self.resize(1280, 720)
        self.setStyleSheet("""
            QMainWindow, QWidget { background-color: #1e1e1e; color: #e0e0e0; }
            QGroupBox {
                border: 1px solid #3a3a3a;
                border-radius: 4px;
                margin-top: 8px;
                padding: 8px;
                font-weight: bold;
            }
            QGroupBox::title {
                subcontrol-origin: margin;
                left: 8px;
                padding: 0 4px;
                color: #b0b0b0;
            }
            QPushButton {
                background-color: #2d2d2d;
                border: 1px solid #4a4a4a;
                border-radius: 3px;
                padding: 5px 10px;
            }
            QPushButton:hover  { background-color: #3a3a3a; }
            QPushButton:pressed{ background-color: #1a1a1a; }
            QComboBox, QLineEdit, QDoubleSpinBox {
                background-color: #2d2d2d;
                border: 1px solid #4a4a4a;
                padding: 3px;
            }
            QLabel { background: transparent; }
        """)
        pg.setConfigOptions(useOpenGL=True, antialias=False,
                            background="#000000", foreground="#b0b0b0")

        # --- display state ---
        self._timebase = 5e-5
        self._vdiv = 3.0
        self._voffset = 0.0
        self._running = True
        self._single_pending = False

        # --- central layout ---
        central = QWidget()
        self.setCentralWidget(central)
        root = QVBoxLayout(central)
        root.setContentsMargins(8, 8, 8, 8)
        root.setSpacing(6)

        status = QHBoxLayout()
        self.scale_lbl = QLabel()
        self.fps_lbl = QLabel("FPS: 0.0")
        self.fps_lbl.setStyleSheet("color: #00FF88;")
        self.state_lbl = QLabel("RUN")
        self.state_lbl.setStyleSheet("color: #00FF88; font-weight: bold;")
        self.backend_lbl = QLabel()
        self.backend_lbl.setStyleSheet("color: #888888;")
        self.meas_lbl = QLabel("")          # per-channel measurements (freq / Vpp / Vdc)
        self.meas_lbl.setStyleSheet("color: #FFD080;")
        status.addWidget(self.state_lbl)
        status.addSpacing(12)
        status.addWidget(self.scale_lbl)
        status.addSpacing(12)
        status.addWidget(self.backend_lbl)
        status.addSpacing(16)
        status.addWidget(self.meas_lbl)
        status.addStretch(1)
        status.addWidget(self.fps_lbl)
        root.addLayout(status)

        body = QHBoxLayout()
        body.setSpacing(8)
        root.addLayout(body, 1)

        self.graph = pg.PlotWidget()
        self.graph.showGrid(x=True, y=True, alpha=0.35)
        self.graph.setLabel("left", "Voltage", units="V")
        self.graph.setLabel("bottom", "Time", units="s")
        self.graph.disableAutoRange()
        self.graph.setMouseEnabled(x=False, y=False)
        self.graph.hideButtons()
        self.graph.setMenuEnabled(False)
        body.addWidget(self.graph, 1)

        self.controls = UserInputPanelQt()
        self.controls.setFixedWidth(340)
        self.controls.register_callback(self._handle_command)
        body.addWidget(self.controls, 0)

        self._ch1_line = self.graph.plot(pen=pg.mkPen(color=(0, 140, 220), width=2))
        self._ch2_line = self.graph.plot(pen=pg.mkPen(color=(220, 120, 180), width=2))
        for line in (self._ch1_line, self._ch2_line):
            line.setClipToView(True)
            # Draw the actual samples connected by straight lines (linear
            # interpolation). 'peak' downsampling drew a min/max envelope that
            # looked like a filled band for dense signals; with 4095 samples per
            # block pyqtgraph renders all points fine (OpenGL is enabled).
            line.setDownsampling(ds=False)
        self._ch_visible = {1: True, 2: True}

        # --- software trigger state (host-side) ---
        # The firmware free-runs (no hardware trigger gating), so we align each
        # incoming block here: find the trigger edge on the source channel and
        # roll every channel by the same offset so the trace locks horizontally.
        self._trig_level_v = 0.0
        self._trig_mode    = "rising"   # "rising" | "falling" | "auto"
        self._trig_source  = 1          # 1 = Ch1, 2 = Ch2
        self._trig_offset  = 0          # last good trigger index (held on no-edge)

        # Latest per-channel measurements: {ch: (freq_hz|None, vpp_v, vrms_v)}.
        self._meas = {1: None, 2: None}
        # Latest raw block per channel: {ch: (samples_raw, time)}. We stash these
        # on every block but only run the (expensive) FFT measurement at the label
        # cadence (~2 Hz) in _tick, instead of once per block. The measurement is
        # only displayed twice a second, so per-block FFTs were pure wasted work.
        self._last_raw = {1: None, 2: None}

        # --- backend ---
        self._mock_mcu: Optional[MockMCU] = None
        if port:
            try:
                import serial  # type: ignore
                transport = serial.Serial(port, 115200, timeout=0.1)
                self.backend_lbl.setText(f"Backend: serial {port}")
            except Exception as e:
                print(f"[main] could not open {port}: {e} - falling back to MockMCU")
                self._mock_mcu = MockMCU(mode="dual")
                transport = self._mock_mcu
                self.backend_lbl.setText("Backend: MockMCU (fallback)")
        else:
            self._mock_mcu = MockMCU(mode="dual")
            transport = self._mock_mcu
            self.backend_lbl.setText("Backend: MockMCU")

        self.bridge = HostBridge(transport)
        self.bridge.register_display_callback(self._on_backend_data)
        self.bridge.start()
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
